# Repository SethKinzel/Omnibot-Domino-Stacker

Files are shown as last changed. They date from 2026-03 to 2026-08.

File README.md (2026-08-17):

# Omnibot Domino Stacker

A modification for the **CrunchLabs Hack Pack Omnibot Forklift** that allows the robot to pick up and stack dominoes.

The project replaces the standard remote-control setup with an **Arduino-based wireless controller** using two joysticks. This allows for **variable-speed movement and rotation**, giving much finer control when positioning the robot and stacking dominoes.

Domino Stacker

## Features

* Wireless control using **NRF24L01** transceiver modules
* Arduino-based remote controller
* Dual joystick control
* Variable-speed forward/reverse/left/right movement
* Variable-speed rotation
* Servo-controlled domino stacking mechanism
* 3D-printed modifications and components

## Parts

### Robot

* **CrunchLabs Hack Pack Omnibot Forklift**
* 1 × Standard **SG90 Micro Servo**
* 1 × NRF24L01 Transceiver Module
* 1 × Decoupling capacitor (10 µF–100 µF recommended)
* Counterweight material (I used large bolts)
* Wires
* Access to a 3D printer

### Remote Control

* Arduino Nano
* 1 × NRF24L01 Transceiver Module
* 1 × Decoupling capacitor (10 µF–100 µF recommended)
* 2 × Joysticks (KY-023 or similar)
* Wires

### NRF24L01 Modules

[NRF24L01 Transceiver Modules on Amazon](https://www.amazon.com/dp/B00LX47OCY/ref=as_li_tl?ie=UTF8&tag=tyche-8392-20&psc=1)

The decoupling capacitors are used to help provide stable power to the NRF24L01 modules.

[100 µF Electrolytic Capacitors – SparkFun](https://www.sparkfun.com/electrolytic-decoupling-capacitors-100uf-25v.html)

This tutorial provides additional information about using the NRF24L01 with Arduino:

[NRF24L01 Arduino Wireless Communication Tutorial](https://www.instructables.com/NRF24L01-Tutorial-Arduino-Wireless-Communication/)

## Arduino Libraries

The project uses the following Arduino libraries:

* **RF24** by TMRh20  
  Install through the Arduino Library Manager or from the [RF24 GitHub repository](https://github.com/tmrh20/RF24/)

* **MapFloat** by radishlogic  
  [MapFloat GitHub repository](https://github.com/radishlogic/MapFloat)

* **OneButton** by Matthias Hertel  
  Install through the Arduino Library Manager or from the [OneButton GitHub repository](https://github.com/mathertel/OneButton)

* **EasyJoystick** by Seth Kinzel  
  Install through the Arduino Library Manager or from the [EasyJoystick GitHub repository](https://github.com/SethKinzel/EasyJoystick)

## Getting Started

### 1. Remove Parts for Installation and Rewiring

Start by removing the parts of the Omnibot that need to be taken off to install the new **lift/domino stacker assembly**.

Removing these parts also gives you better access to the electronics and wiring, which you will need for the rewiring steps that follow.

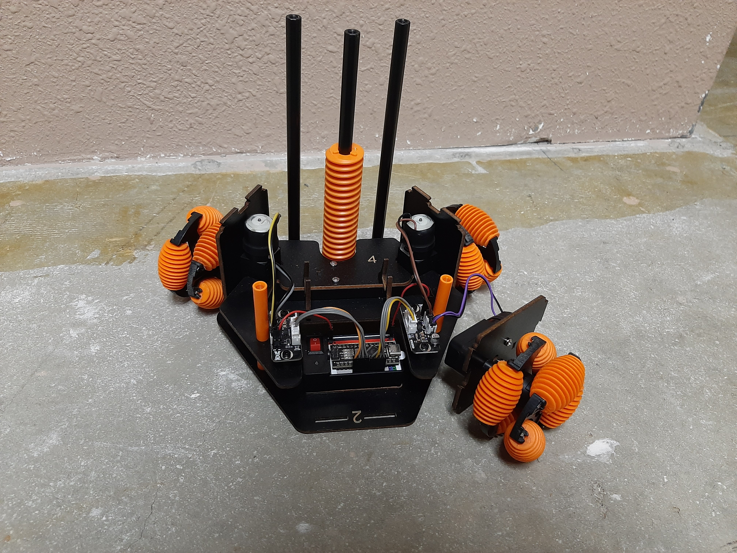
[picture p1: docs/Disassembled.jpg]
Omnibot disassembled


### 2. Print the 3D Parts

Print the following files from the `3D` folder:
* Main Body.stl
* Slider.stl
* `DOMNO_Servo_Horn.stl` from the line following domino robot (2nd hackpack). I have included it here.
* Domino.stl  
I had success printing these standing upright with a small brim, but there might be other ways to do it.
Do a few small batches first, and make sure that they stand up and don't get caught.
Be sure to use enough elephant foot compensation.  
The robot takes 70 dominoes, but it might be good to have a few extra.

* (optional) Magazine.stl  
Allows the robot to stack multiple tiles of dominoes without reloading.  
You can stack multiple magazines on top of each other, until it gets too heavy.  
Print upside down, and be sure to block support from the holes in the four corners.

* (optional) folder `3D/Different size dominoes`
Different size dominoes

### 3. Install the new lift/domino mechanism

Assemble as shown:

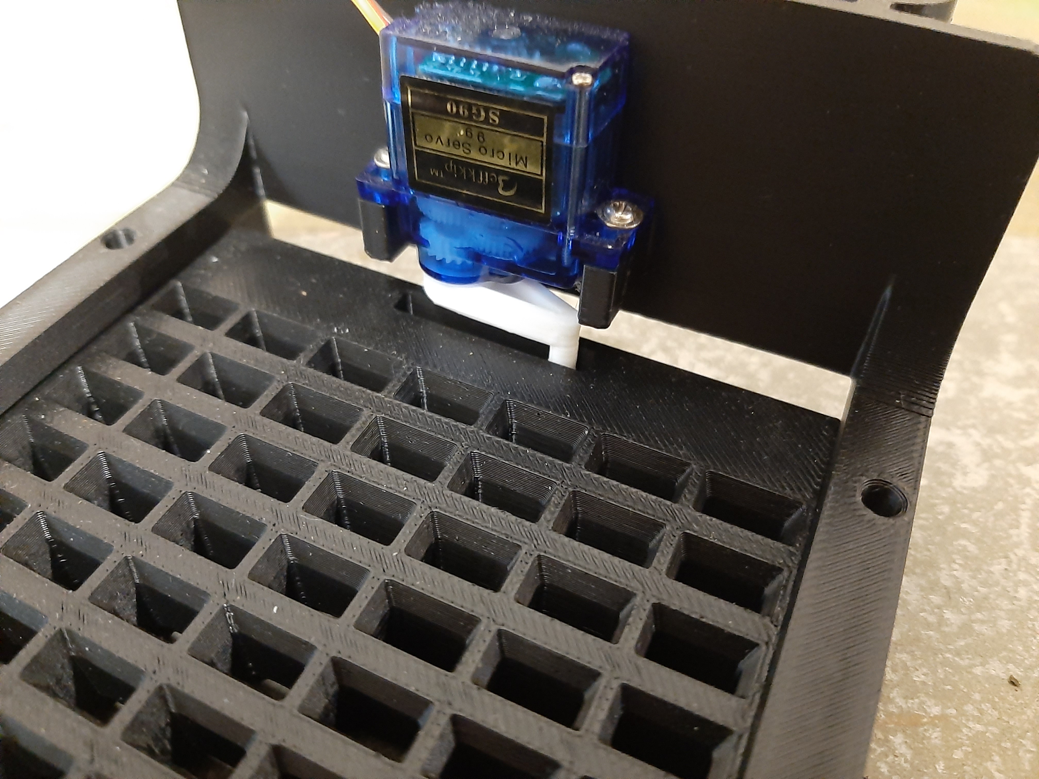
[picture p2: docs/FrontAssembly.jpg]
How to assemble


If using the magazine, put the side with the narrow border towards the robot.

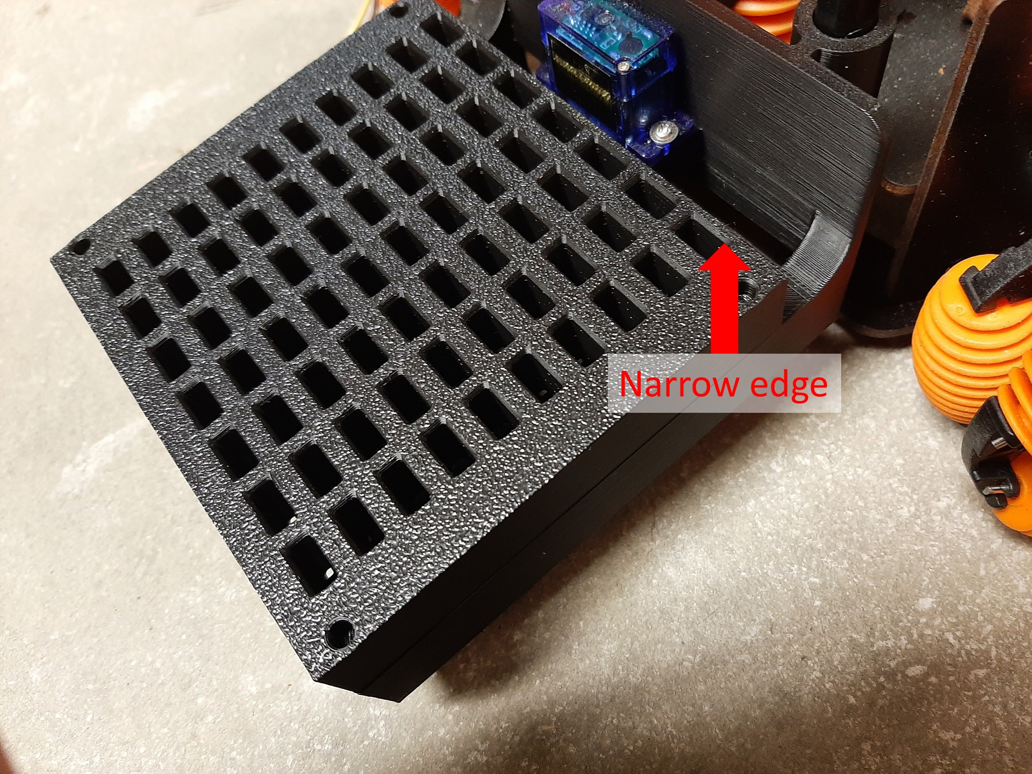
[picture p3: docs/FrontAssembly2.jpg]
How to install magazine


### 4. Rewire the Omnibot

* Swap ribbon cables

  The Domino Stacker uses a servo, which occupies one of the Arduino's hardware timer outputs. The stock Omnibot wiring uses PWM on pin 9, which conflicts with the servo.

  To avoid changing the existing ribbon cables, the motor assignments are rearranged so that the three drive motors use PWM-capable pins while the lift motor (which only needs full-speed up/down movement) uses the remaining output.

  The Omnibot has two ribbon cables connecting the Arduino board to the motor driver boards.

  **Swap the two ribbon cables on the motor driver boards only.**

  > **Important:** Leave the Arduino ends plugged in exactly as they are. Only unplug and swap the ends connected to the two motor driver boards.

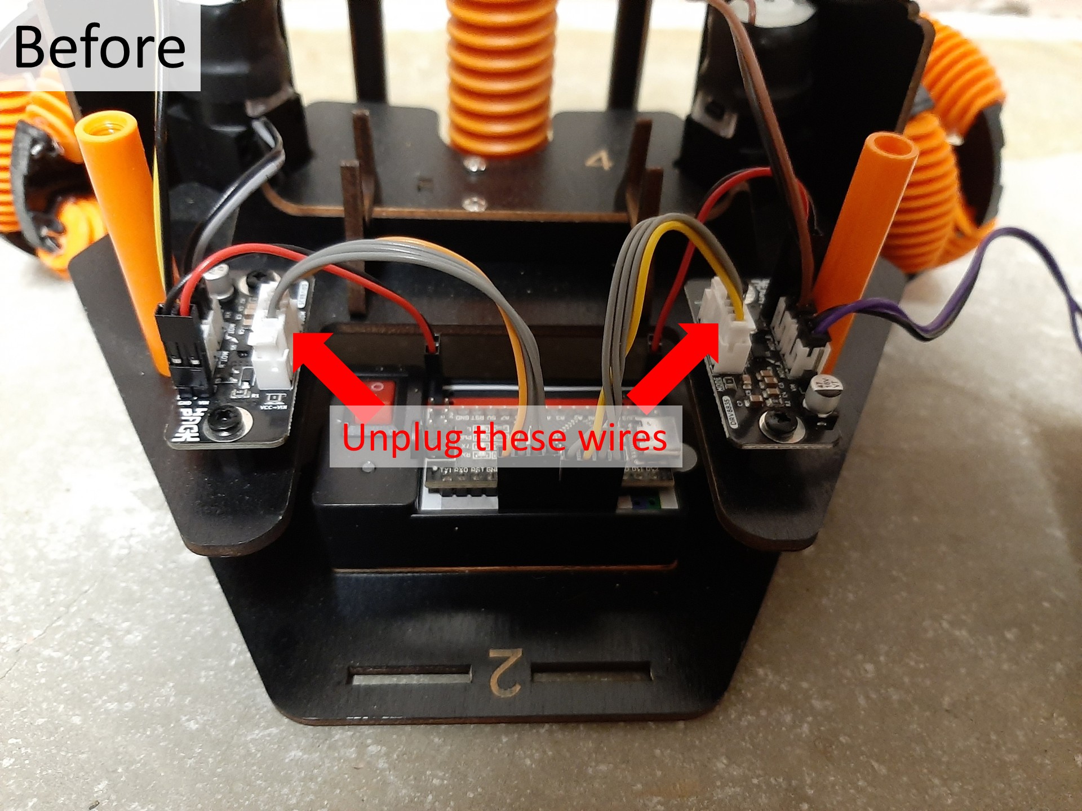
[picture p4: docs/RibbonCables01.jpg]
Switching the ribbon cables
  
  
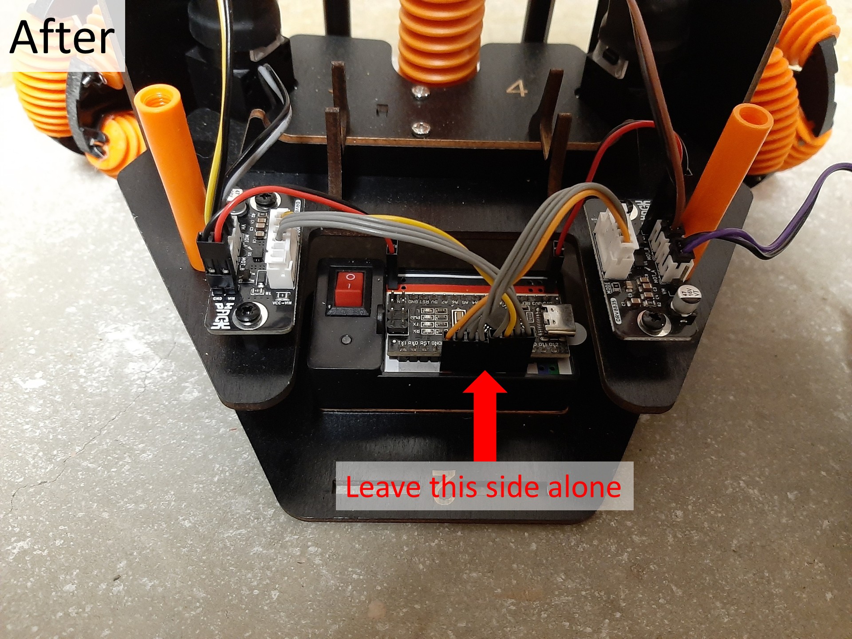
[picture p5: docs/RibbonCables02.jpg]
Switching the ribbon cables
  

* Swap yellow/gray motor cables

  On the **left motor driver board**, swap these two cables:

  * Yellow cable from **Motor 1**
  * Gray cable from the **Lift Motor**

  After swapping them, the motor connections should match the new pin assignments used by the software.

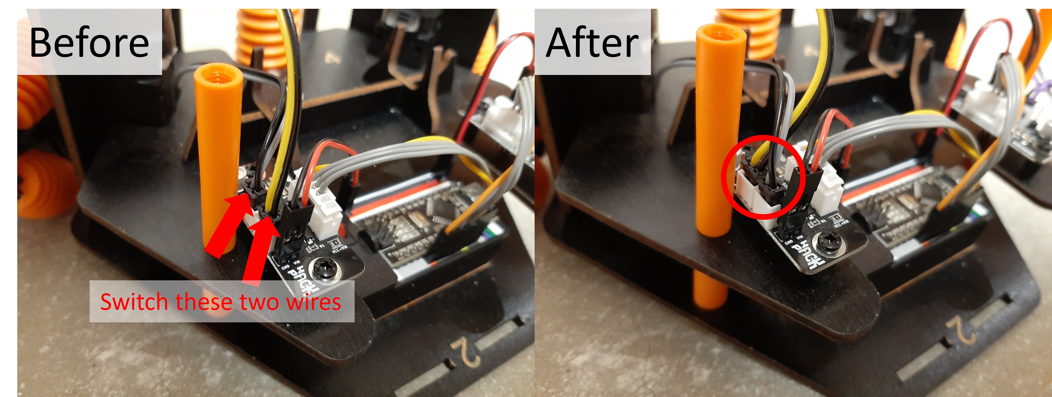
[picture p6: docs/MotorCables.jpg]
Switching the motor cables
  

* Add the Receiver and Servo

  Once the rewiring is complete, add the **receiver** and the **servo** according to the wiring diagram.

  Make sure all connections match the diagram before powering on the robot.

  #### ⚠️ Warning – NRF24L01 Power

  The **NRF24L01 requires 3.3V**. Connect VCC to the Arduino's **3.3V pin, NOT 5V**.

  I connected both the transceiver and capacitor to the 3.3V pin on the Arduino using a simple Y-shaped wire made by soldering **one male wire to two female wires**.

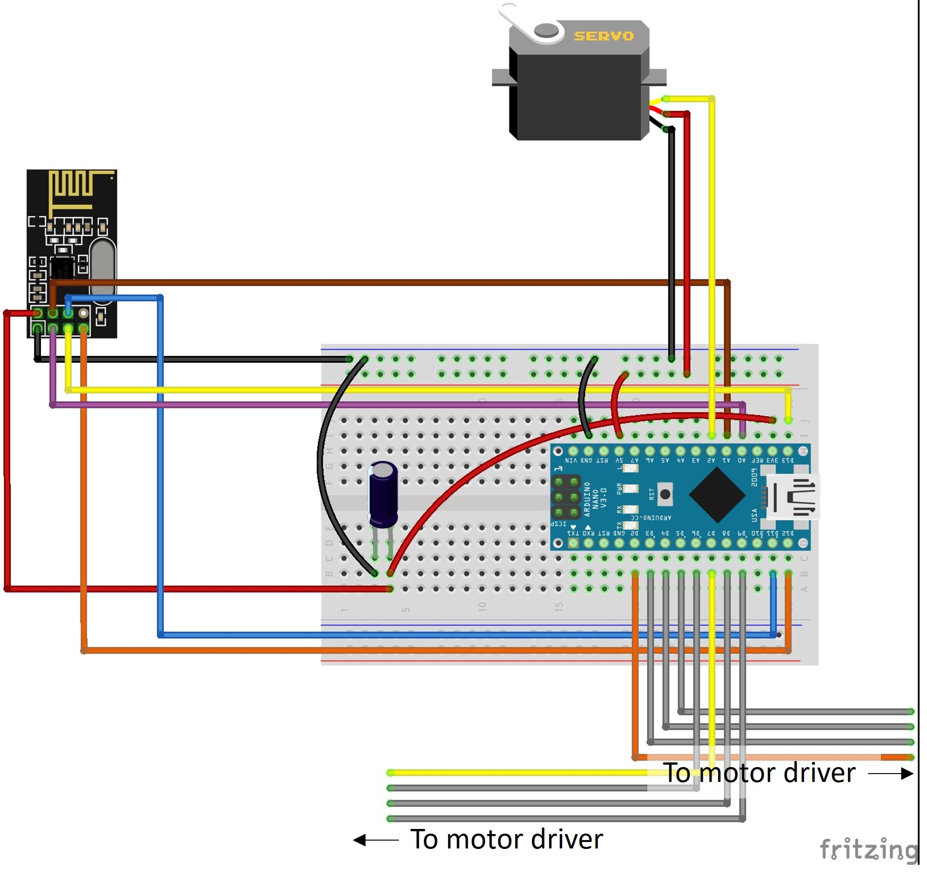
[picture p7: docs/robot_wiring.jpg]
Robot wiring diagram
  

### 5. Add Counterweight

Reassemble the robot and install a counterweight at the back. The counterweight helps maintain enough friction on the back wheel.

### 6. Build the remote controller

Follow the wiring diagram:

#### ⚠️ Warning – NRF24L01 Power

The **NRF24L01 requires 3.3V**. Connect VCC to the Arduino's **3.3V pin, NOT 5V**.

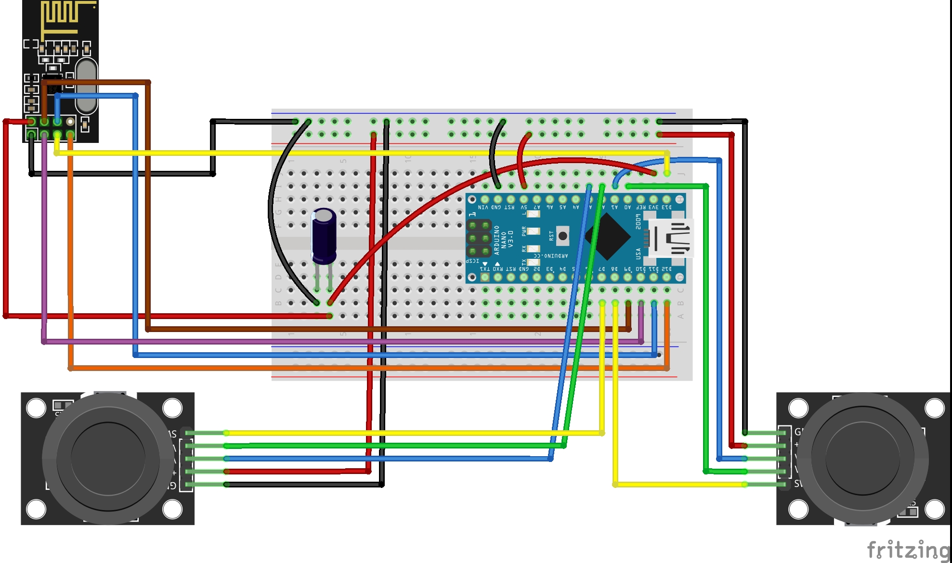
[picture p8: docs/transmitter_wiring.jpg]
Remote control wiring diagram


### 7. Install the required libraries

Install all of the libraries listed above using the Arduino Library Manager or their respective GitHub repositories.

### 8. Upload the Arduino sketches

Upload `Omnibot_Domino_Stacker.ino` to the Omnibot, and `OmniRemote_Transmitter.ino` to the remote control.

### 9. Power on and connect

Turn on the Omnibot and remote controller. The NRF24L01 modules should establish a wireless connection, allowing the robot to be controlled using the joysticks.

## Controls

| Control | Function |
| --- | --- |
| Left joystick | Movement |
| Right joystick left/right | Rotation |
| Right joystick up/down | Raise/lower dominoes |
| Right joystick button | Drop dominoes / reset domino holder |

## Fine-tuning

You may need to adjust the `SERVO_DROP` and `SERVO_RESET` constants in `Omnibot_Domino_Stacker/config.h` to fine-tune the servo positions.

## Optional Components

The following components are **completely optional** and are disabled by default. They do not affect the basic operation of the robot.

### LCD

I had an I2C LCD (from the label maker Hack Pack) already attached to the Arduino I used for the remote control, so I added support for it. It simply displays **"Remote Control"**.

You do not need an LCD to use the project.

The LCD can be enabled or disabled by editing the following line in `OmniRemote_Transmitter.ino`:

```cpp
#define USE_LCD 0
```

Set this to `1` to enable the LCD:

```cpp
#define USE_LCD 1
```

Wire the I2C LCD to the I2C port on A4 and A5

hd44780 library by Bill Perry — required only when USE_LCD is set to 1  
Install through the Arduino Library Manager or from the [hd44780 GitHub repository](https://github.com/duinoWitchery/hd44780)

If you are not using an LCD, you **do not need to install the hd44780 library**.

### LED Strip

There is also an optional LED strip (taken from the sand garden Hack Pack) that displays a simple color pattern. The LEDs are purely decorative and are not required for controlling the robot.

LED support can be enabled by uncommenting this line in `OmniRemote_Config.h`:

```cpp
#define USELEDS
```

When LED support is not needed, leave the line commented out.

Wire the led strip to pin 2

FastLED library by Daniel Garcia - required only when USELEDS is defined.  
Install through the Arduino Library Manager or from the [FastLED GitHub repository](https://github.com/FastLED/FastLED)

If `USELEDS` is not defined, you **do not need to install the FastLED library**.

## Project Status

This project is a personal modification of the CrunchLabs Hack Pack Omnibot Forklift.

The repository contains the hardware modifications, Arduino code, and 3D-printed parts needed to build the domino stacker.

## Credits

* **CrunchLabs** – Omnibot Hack Pack Forklift
* **TMRh20** – RF24 library
* **radishlogic** – MapFloat library
* **Matthias Hertel** – OneButton library
* **Seth Kinzel** – EasyJoystick library
* **Bill Perry** – hd44780 library
* **Daniel Garcia** – FastLED library

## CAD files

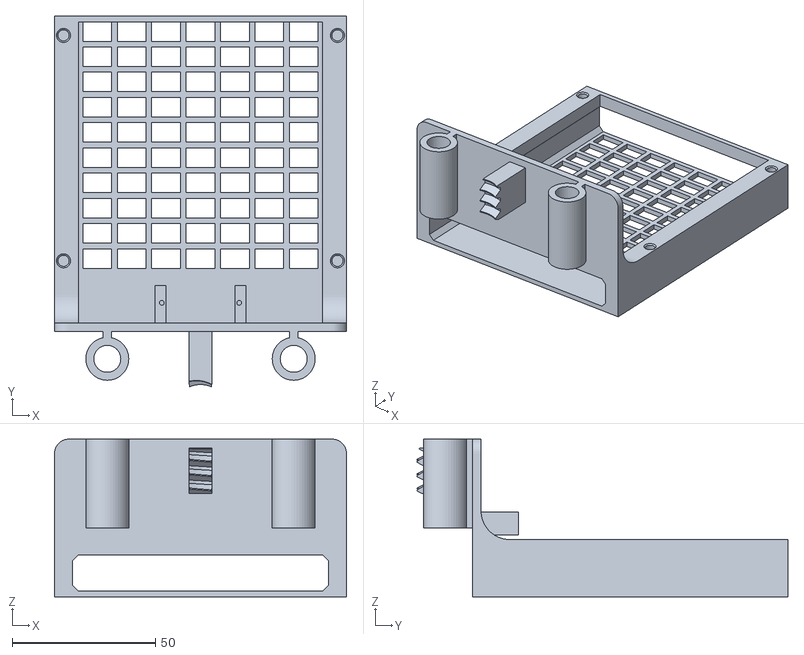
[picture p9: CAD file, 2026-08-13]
3D/Main Body.stl
101.8 x 129.3 x 55.0

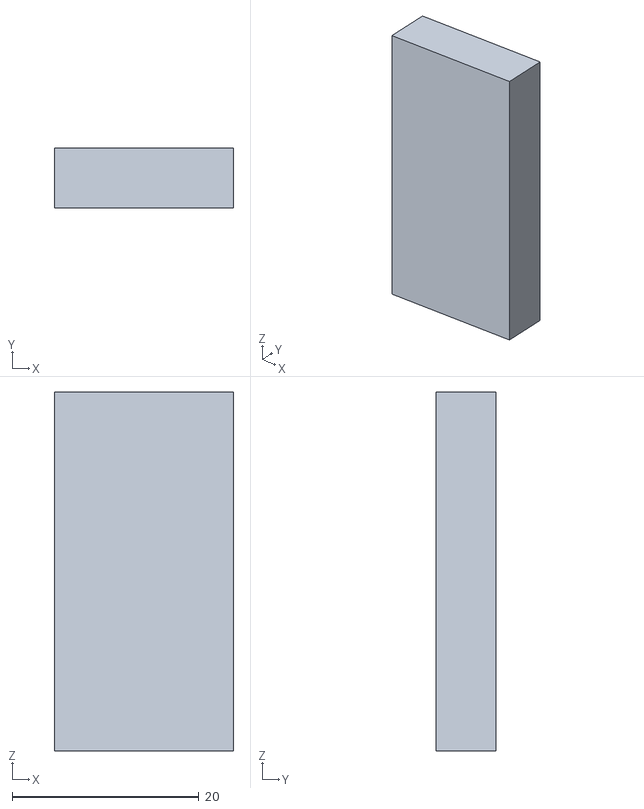
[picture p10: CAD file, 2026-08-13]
3D/Different size dominoes/Size -1.stl
19.2 x 6.40 x 38.4

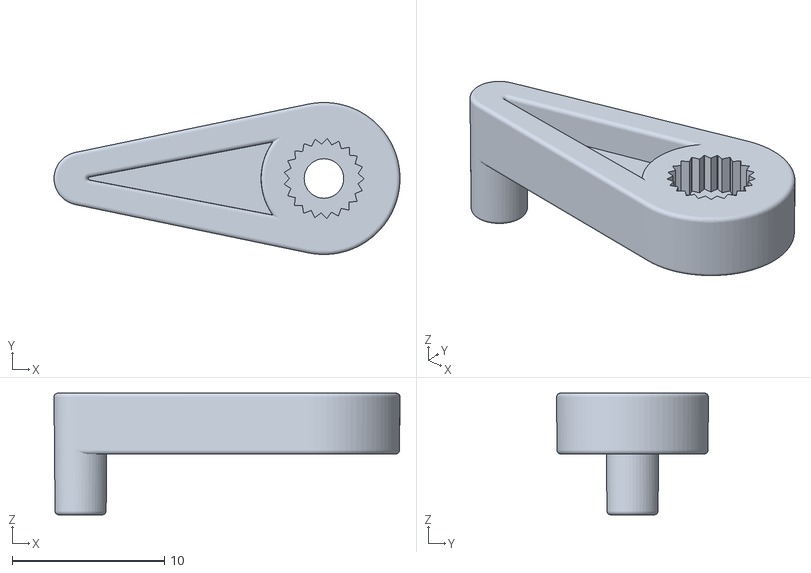
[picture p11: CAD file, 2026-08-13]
3D/DOMNO_Servo_Horn.stl
22.7 x 9.99 x 8.00

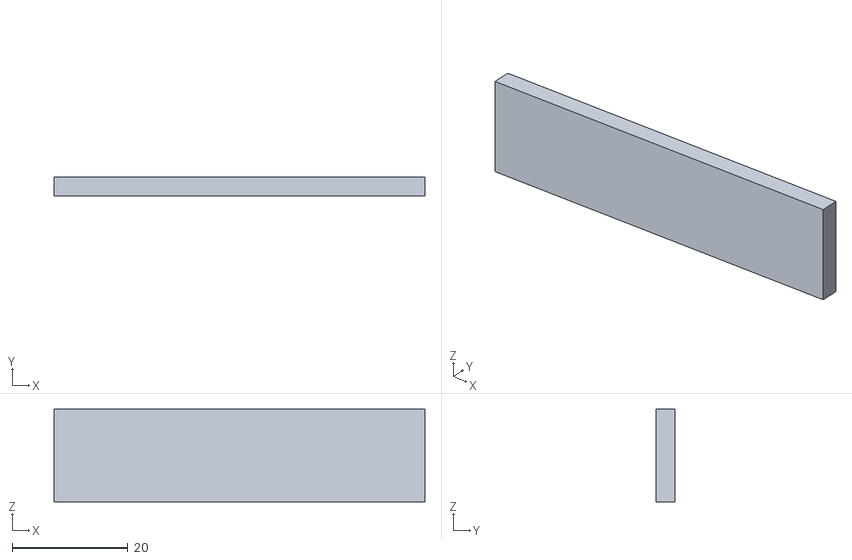
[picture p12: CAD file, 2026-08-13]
3D/Different size dominoes/Wide Domino 3.stl
64.0 x 3.20 x 16.0

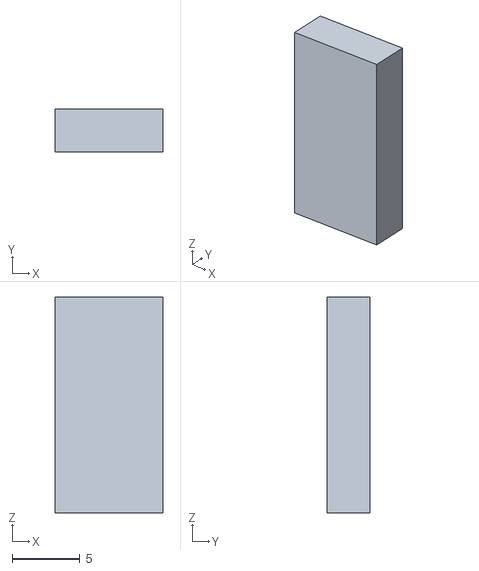
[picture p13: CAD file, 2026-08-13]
3D/Domino.stl
8.00 x 3.20 x 16.0

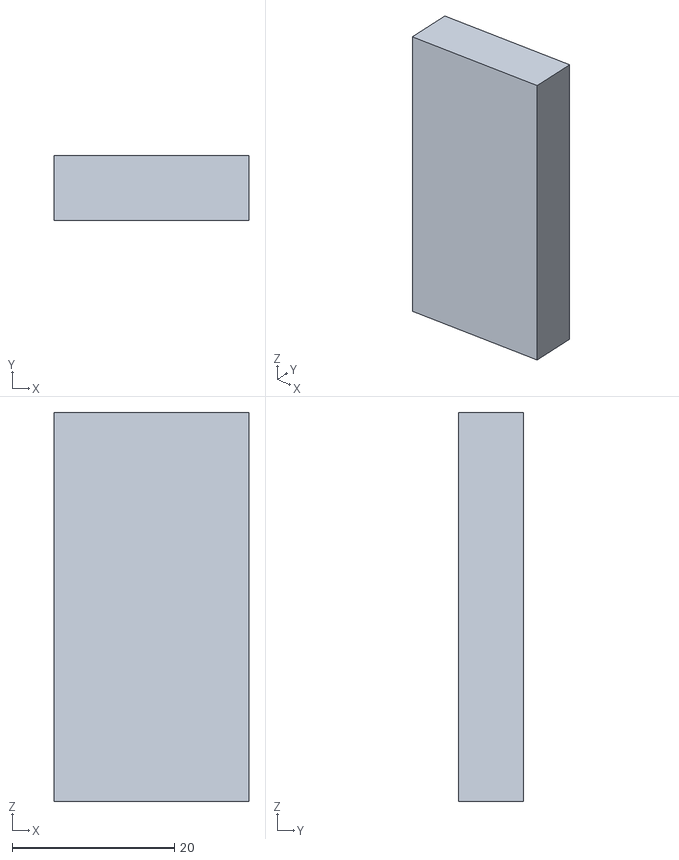
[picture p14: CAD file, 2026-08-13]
3D/Different size dominoes/Normal Size.stl
24.0 x 8.00 x 48.0

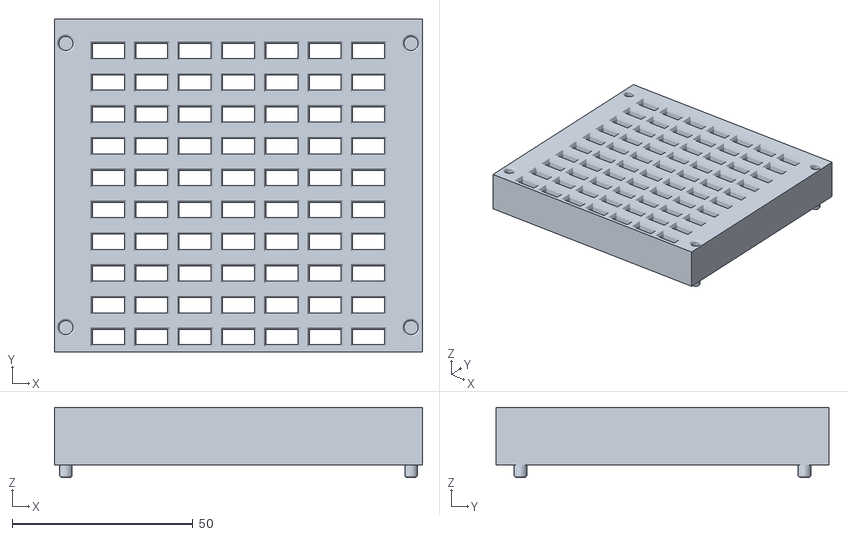
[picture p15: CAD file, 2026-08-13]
3D/Magazine.stl
101.8 x 92.1 x 19.5

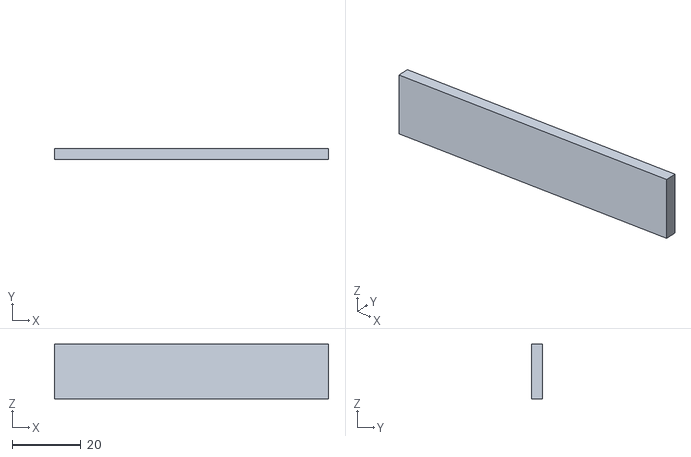
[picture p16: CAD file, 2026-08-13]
3D/Different size dominoes/Wide Domino 4.stl
80.0 x 3.20 x 16.0

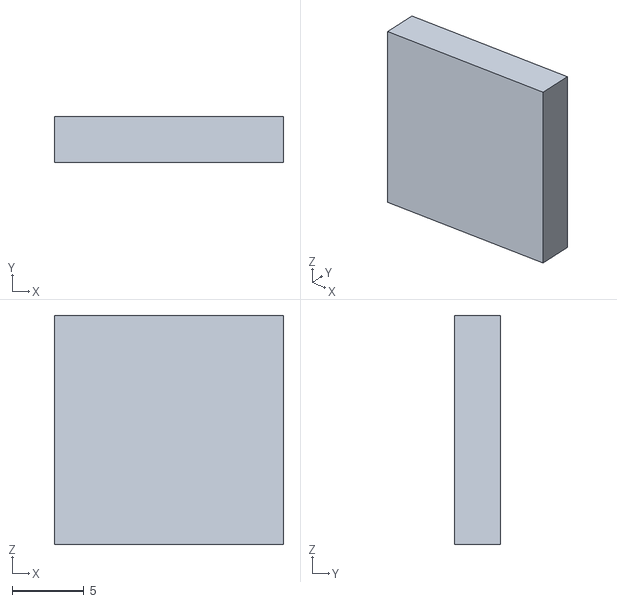
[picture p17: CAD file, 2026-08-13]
3D/Different size dominoes/Wide Domino 1.stl
16.0 x 3.20 x 16.0

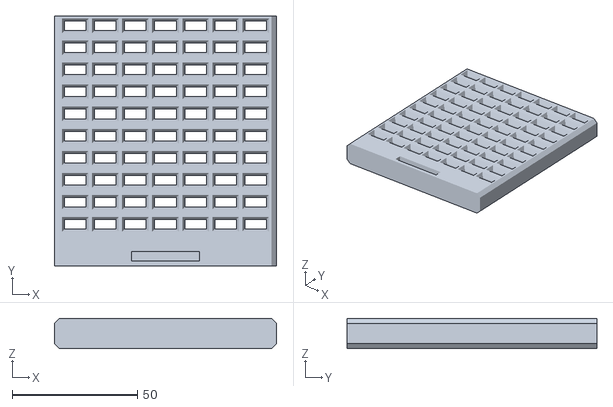
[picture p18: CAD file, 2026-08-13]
3D/Slider.stl
88.6 x 99.8 x 12.0

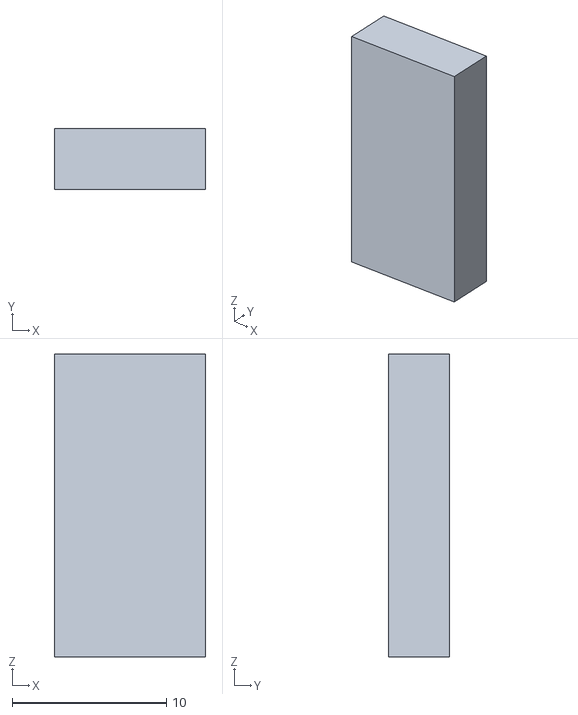
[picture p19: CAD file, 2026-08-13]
3D/Different size dominoes/Size -4.stl
9.83 x 3.93 x 19.7

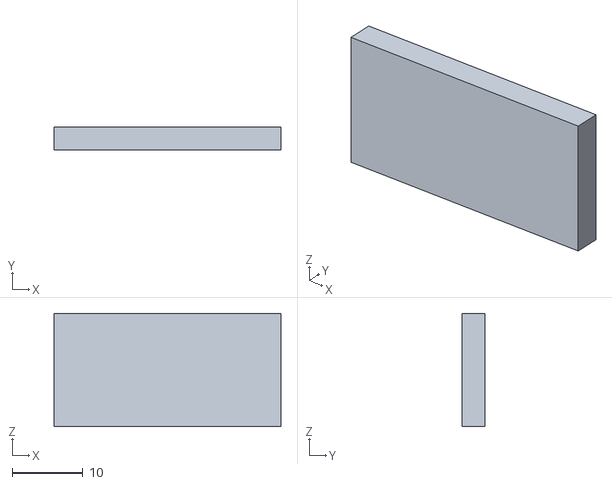
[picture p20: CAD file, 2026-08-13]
3D/Different size dominoes/Wide Domino 2.stl
32.0 x 3.20 x 16.0

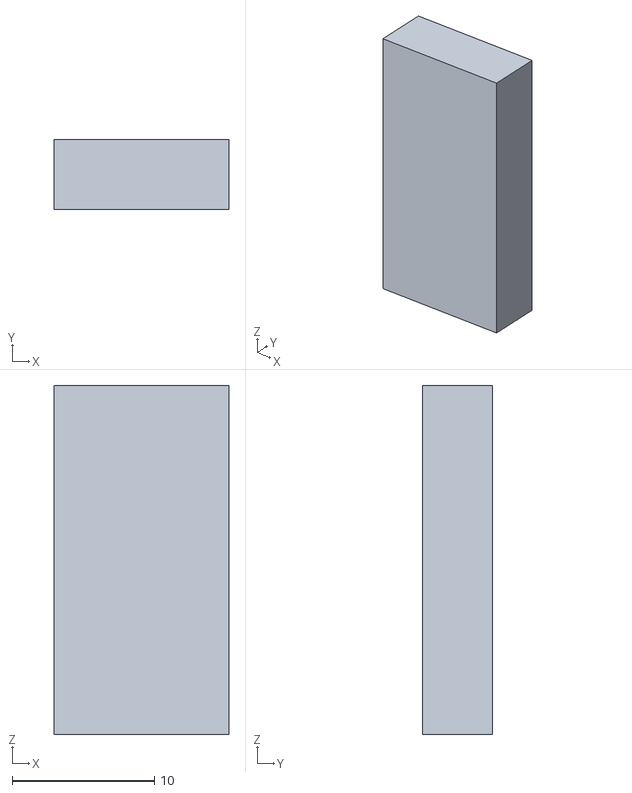
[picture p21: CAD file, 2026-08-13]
3D/Different size dominoes/Size -3.stl
12.3 x 4.92 x 24.6

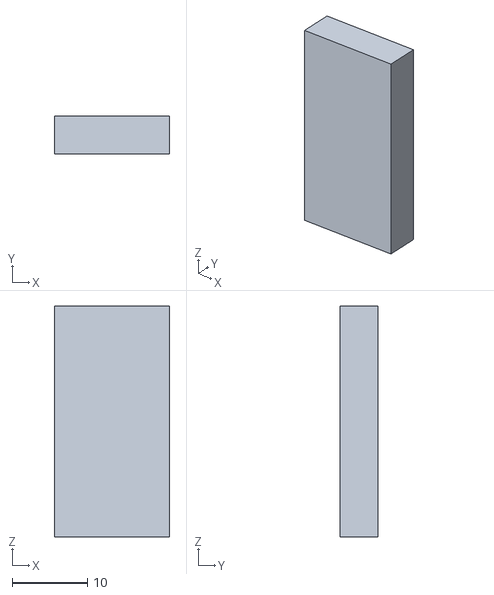
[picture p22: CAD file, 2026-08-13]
3D/Different size dominoes/Size -2.stl
15.4 x 5.12 x 30.7

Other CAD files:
3D/Different size dominoes/Size 1.stl
3D/Different size dominoes/Size 2.stl
3D/Different size dominoes/Size 3.stl
3D/Different size dominoes/Size 4.stl

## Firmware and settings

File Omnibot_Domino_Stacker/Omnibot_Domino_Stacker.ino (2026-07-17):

/*
A hack to the CrunchLabs Hack Pack Omnibot Forklift that allows it to stack dominoes.  
It uses an arduino and two joysticks as the remote control to allow for variable-speed movement and rotation  
*/

#include "config.h"
#include <SPI.h>
#include <RF24.h>
#include <nRF24L01.h>
#include "RC_Payload.h"
#include <Servo.h>
#include <MapFloat.h>

#define SIN60 0.86602540378443864676372317075294

//>>>>>>>>>>>>>>>>>>>>>>>>>> KEY ROBOT VARIABLES <<<<<<<<<<<<<<<<<<<<<<<<<<<<<<<
// drive vector (in velocities) {v_x, v_y, omega}
struct VECTOR {
  float x, y, o;
};

VECTOR vSpeed;
// for forklift, -1 for lower, 0 for stay, 1 for move up
int moveFork = 0;

// stores each calculated wheel speed for a given commanded vector {w1, w2, w3}.
float wheelSpeeds[3];

// receiver
RF24 radio(CE_PIN, CSN_PIN); // CE, CSN
// servo
Servo servo1;

// >>>>>>>>>>>>>>>>>>>>>>>>>>>>>>>>> SETUP <<<<<<<<<<<<<<<<<<<<<<<<<<<<<<<<<<<<<
void setup() {
  servo1.attach(SERVO_PIN);
  servo1.write(SERVO_RESET);

  radio.begin();
  radio.setPALevel(RF24_PA_MIN);
  radio.setPayloadSize(sizeof(payload));
  radio.openReadingPipe(0, address);
  radio.startListening();
}



// >>>>>>>>>>>>>>>>>>>>>>>>>>>>>>>>> LOOP <<<<<<<<<<<<<<<<<<<<<<<<<<<<<<<<<<<<<<
void loop() {
  handleRadio();
  moveBot();
}



// >>>>>>>>>>>>>>>>>>>>> RADIO COMMAND PROCESSING <<<<<<<<<<<<<<<<<<<<<<<<<<<<<<
void handleRadio() {
  if (!radio.available()) return; // only run the rest of the function if there is new data
  radio.read(&payload, sizeof(payload));

  //set x, y, and omega vectors
  int32_t x = payload.lx - 512; // needs int32 for radius calculation
  int32_t y = payload.ly - 512;
  int32_t radius = sqrt(x*x + y*y); // pythagorean theorem
  if (abs(radius < joystickCenterThreshold)) {
    x = 0;
    y = 0;
  }
  int o = payload.rx - 512;
  if (abs(o) < joystickCenterThreshold) o = 0;

  const int xyScaling = 430;
  const int oScaling = 500;
  vSpeed.x = mapFloat(x, -xyScaling, xyScaling, 1, -1);
  vSpeed.y = mapFloat(y, -xyScaling, xyScaling, 1, -1);
  vSpeed.o = mapFloat(o, -oScaling, oScaling, -1, 1);

  if(payload.ry > 512 + joystickCenterThreshold) { //Fork Up
    moveFork = 1;
  } else if(payload.ry < 512 - joystickCenterThreshold) { //Fork Down
    moveFork = -1;
  } else {
    moveFork = 0;
  }

  if(payload.rb1) {
    servo1.write((servo1.read() == SERVO_RESET) ? SERVO_DROP : SERVO_RESET);
  }
}


// >>>>>>>>>>>>>>>>>>>>>>>> ROBOT ACTION FUNCTIONS <<<<<<<<<<<<<<<<<<<<<<<<<<<<<
// prepare motors to coorinate bot movements
void moveBot(){
  getWheelSpeeds();
  driveWheels();
  driveLift();
}

// >>>>>>>>>>>>>>>>>>>>>>>>>> INVERSE KINEMATICS <<<<<<<<<<<<<<<<<<<<<<<<<<<<<<<
// calculates speed of each wheel based of commanded speed vector. Forumlas are in the linked reading!
void getWheelSpeeds() {
  wheelSpeeds[2] = -0.5 * vSpeed.x + SIN60 * vSpeed.y + vSpeed.o;
  wheelSpeeds[0] = -0.5 * vSpeed.x - SIN60 * vSpeed.y + vSpeed.o;
  wheelSpeeds[1] =  1.0 * vSpeed.x + vSpeed.o;
}

// Addresses motor controllers to drive wheels at caclulated speeds
void driveWheels(){  
  // drive all motors at calculated speeds
  float topWheelSpeed = max(max(abs(wheelSpeeds[0]), abs(wheelSpeeds[1])), abs(wheelSpeeds[2]));
  int16_t intSpeeds[3];

  for(int8_t i = 0; i < 3; i++) {
    if (topWheelSpeed > 1) {
      wheelSpeeds[i] = wheelSpeeds[i] / topWheelSpeed;
    }
    wheelSpeeds[i] = mapFloat(wheelSpeeds[i], -1, 1, -255, 255);
    intSpeeds[i] = constrain(wheelSpeeds[i], -255, 255);
    if((flipM1 && i == 0) || (flipM2 && i == 1) || (flipM3 && i == 2)) {
      intSpeeds[i] = - intSpeeds[i];
    }
  }

  if(intSpeeds[0] < 0){
    digitalWrite(M1_DIR, LOW);
  } else {
    digitalWrite(M1_DIR, HIGH);
  }
  analogWrite(M1_PWM, abs(intSpeeds[0]));

  if(intSpeeds[1] < 0){
    digitalWrite(M2_DIR, LOW);
  } else {
    digitalWrite(M2_DIR, HIGH);
  }
  analogWrite(M2_PWM, abs(intSpeeds[1]));

  if(intSpeeds[2] < 0){
    digitalWrite(M3_DIR, LOW);
  } else {
    digitalWrite(M3_DIR, HIGH);
  }
  analogWrite(M3_PWM, abs(intSpeeds[2]));
}

// Moves lift motor. full forward, full back, or stopped.
void driveLift(){
  if(flipM4){
    if(moveFork > 0){
      digitalWrite(LIFT_DIR, LOW);
      analogWrite(LIFT_PWM, 255);
    } else if(moveFork < 0){
      digitalWrite(LIFT_DIR, HIGH);
      analogWrite(LIFT_PWM, 255);
    } else{
      digitalWrite(LIFT_DIR, HIGH);
      analogWrite(LIFT_PWM, 0);
    }
  } else {
    if(moveFork > 0){
      digitalWrite(LIFT_DIR, HIGH);
      analogWrite(LIFT_PWM, 255);
    } else if(moveFork < 0){
      digitalWrite(LIFT_DIR, LOW);
      analogWrite(LIFT_PWM, 255);
    } else{
      digitalWrite(LIFT_DIR, LOW);
      analogWrite(LIFT_PWM, 0);
    }
  }
}

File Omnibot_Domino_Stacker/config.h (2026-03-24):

const int joystickCenterThreshold = 75;
// motor flipping
bool flipM1 = false;
bool flipM2 = false;
bool flipM3 = false;
bool flipM4 = true;

// servo positions
const int SERVO_DROP = 92;
const int SERVO_RESET = 74;

// pin definitions
#define M1_DIR 7
#define M1_PWM 6
#define M2_DIR 2
#define M2_PWM 3
#define M3_DIR 4
#define M3_PWM 5

#define LIFT_DIR 8
#define LIFT_PWM 9

#define CE_PIN A0
#define CSN_PIN A1

#define SERVO_PIN A2

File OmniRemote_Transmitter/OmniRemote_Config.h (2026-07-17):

#ifndef SK_REMOTEPINDEFINITIONS_h
#define SK_REMOTEPINDEFINITIONS_h

#include <Arduino.h>


// Pin Definitions
constexpr int8_t LEFT_JOYSTICK_X_PIN = A3;
constexpr int8_t LEFT_JOYSTICK_Y_PIN = A2;
constexpr int8_t RIGHT_JOYSTICK_X_PIN = A1;
constexpr int8_t RIGHT_JOYSTICK_Y_PIN = A0;
constexpr int8_t LEFT_BUTTON_1_PIN = 7;
constexpr int8_t RIGHT_BUTTON_1_PIN = 8;
constexpr int8_t LED_DATA_PIN = 2;
constexpr int8_t CE_PIN = 10;
constexpr int8_t CSN_PIN = 9;
constexpr int8_t BUZZER_PIN = 3;
constexpr int8_t RANDOM_PIN = A6;

// Configuration
constexpr bool LEFT_JOYSTICK_X_FLIPED = true;
constexpr bool LEFT_JOYSTICK_Y_FLIPED = false;
constexpr bool RIGHT_JOYSTICK_X_FLIPED = false;
constexpr bool RIGHT_JOYSTICK_Y_FLIPED = true;

constexpr int NUM_LEDS = 8;          //Number of LEDs in the bar.
// #define USELEDS // uncomment this line if you have an led bar.

#endif

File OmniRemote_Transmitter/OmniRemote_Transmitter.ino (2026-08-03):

// Libraries
#include <SPI.h>
#include <RF24.h>
#include <nRF24L01.h>

#include <OneButton.h>
#include "RC_Payload.h"
#include "OmniRemote_Config.h"


#pragma region SERIAL FUNCTIONS

  // In your code, rather than using Serial.print() or Serial.println(), use their aliases defined below (e.g., SERIAL_PRINTLN()):

#define USE_SERIAL 0  // 1 or 0 to tell whether or not to print stuff to the serial monitor.
                      // Set to 1 when testing and back to 0 when done testing.

#if USE_SERIAL
  #define SERIAL_PRINT(x)     Serial.print(x)
  #define SERIAL_PRINTLN(x)   Serial.println(x)
  #define SERIAL_BEGIN(baud)  Serial.begin(baud)

  void printSerial() {
    Serial.print(F("lx: "));
    printWithSpaces(payload.lx, 4);
    Serial.print(F(", ly: "));
    printWithSpaces(payload.ly, 4);
    Serial.print(F(", rx: "));
    printWithSpaces(payload.rx, 4);
    Serial.print(F(", ry: "));
    printWithSpaces(payload.ry, 4);
    Serial.print(F(", lb1: "));
    printWithSpaces(payload.lb1, 1);
    Serial.print(F(", rb1: "));
    printWithSpaces(payload.rb1, 1);
    Serial.println();
  }

  void printWithSpaces(int16_t val, int16_t spaces) {
    String str = String(val);
    for (int16_t i = str.length(); i < spaces; i++) {
      Serial.print(" ");
    }
    Serial.print(str);
  }

#else
  #define SERIAL_PRINT(x)
  #define SERIAL_PRINTLN(x)
  #define SERIAL_BEGIN(baud)
  #define printSerial()
  #define printWithSpaces(val, spaces)
#endif

#pragma endregion SERIAL FUNCTIONS

#pragma region LCD_FUNCTIONS

#define USE_LCD 0 // 1 or 0 to tell whether or not to use a lcd

#if USE_LCD
  #include <Wire.h>
  #include <hd44780.h>                        // main hd44780 header
  #include <hd44780ioClass/hd44780_I2Cexp.h>  // i2c expander i/o class header
  hd44780_I2Cexp lcd; // declare lcd object: auto locate & auto config expander chip
  #define LCD_PRINT(x)     lcd.print(x)
  #define LCD_BEGIN(x, y)  lcd.begin(x, y)
#else
  #define LCD_PRINT(x)
  #define LCD_BEGIN(x, y)
#endif


#pragma endregion LCD_FUNCTIONS

#pragma region LedDisplayClass
#ifdef USELEDS

/////////////////////////////////////////////////////////////////////////////////////////////////////////////////////////////////////////////////////////
/*
This is a class that contains all the functions and data required to handle the LED display bar.
*/
/////////////////////////////////////////////////////////////////////////////////////////////////////////////////////////////////////////////////////////
#include <FastLED.h>                        //Controls the RGB LEDs
const int MAX_BRIGHTNESS = 40;  //Brightness values are 8-bit for a max of 255 (the range is [0-255]), this sets default maximum to 40 out of 255.

class LedDisplay {
private:
  CRGB leds[NUM_LEDS];        //array that holds the state of each LED

public:
  //This is the constructor. It's called when a new instance of the class is created, and handles setting things up for use.
  LedDisplay() {              
    FastLED.addLeds<WS2812B, LED_DATA_PIN, GRB>(leds, NUM_LEDS);
    FastLED.setBrightness(MAX_BRIGHTNESS);
    FastLED.clear();
  }

/**
 * @brief Animates an LED bouncing pattern during the homing process and flashes green when homing is complete.
 *
 * This function animates a bouncing light pattern on the LEDs to indicate that the gantry is in the process of homing. 
 * Once homing is complete, the LEDs flash green to signal completion. The function can block execution briefly during the 
 * flashing portion after homing is done.
 *
 * @param homingComplete A boolean flag indicating whether the homing process is complete. If set to false, the animation continues. 
 * If set to true, the LEDs flash green to indicate completion.
 *
 * The animation consists of a bouncing light pattern with a color that changes over time. When the gantry finishes homing, 
 * the LEDs flash green in a blocking manner for a brief period.
 */
  void homingSequence(bool homingComplete = false) {
    static unsigned long lastUpdate = 0;

    const byte fadeAmount = 150;
    const int ballWidth = 2;
    const int deltaHue  = 4;

    static byte hue = HUE_RED;
    static int direction = 1;
    static int position = 0;
    static int multiplier = 1;

    FastLED.setBrightness(MAX_BRIGHTNESS);

    if (!homingComplete) {                      //If the homing sequence is not complete, animate this pattern.
      if (millis() - lastUpdate >= 100) {
        hue += deltaHue;
        position += direction;

        if (position == (NUM_LEDS - ballWidth) || position == 0) direction *= -1;

        for (int i = 0; i < ballWidth; i++) {
          leds[position + i].setHue(hue);
        }

        // Randomly fade the LEDs
        for (int j = 0; j < NUM_LEDS; j++) {
          //if (random(10) > 3)
          leds[j] = leds[j].fadeToBlackBy(fadeAmount);  
        }
        FastLED.show();
        lastUpdate = millis();
      }
    } else {                                    //if the homing sequence is complete, indicate that by flashing the LEDs briefly.
      for (int i = 0; i < NUM_LEDS; i++) {
        leds[i] = CRGB::Green;
      }
      
      for (int j = 0; j < 8; j++) {
        FastLED.setBrightness(constrain(MAX_BRIGHTNESS * multiplier, 0, MAX_BRIGHTNESS));
        multiplier *= -1;
        FastLED.show();
        delay(100);
      }
    }
  }
};

LedDisplay display;  // Create an instance of the LedDisplay class that controls the RGB LEDs.

#endif
#pragma endregion LedDisplayClass

// Objects
OneButton leftButton1;
OneButton rightButton1;

RF24 radio(CE_PIN, CSN_PIN); // CE, CSN


void setup() {
  SERIAL_BEGIN(115200);
  LCD_BEGIN(16, 2);
  LCD_PRINT("Remote Control");
  
  radio.begin();
  radio.setPALevel(RF24_PA_MIN);
  radio.setPayloadSize(sizeof(payload));
  radio.openWritingPipe(address);
  radio.stopListening();
  #ifdef USELEDS
    FastLED.clear();            //clear the LEDs
    FastLED.show();
  #endif
  pinMode(LEFT_JOYSTICK_X_PIN, INPUT);
  pinMode(LEFT_JOYSTICK_Y_PIN, INPUT);
  pinMode(RIGHT_JOYSTICK_X_PIN, INPUT);
  pinMode(RIGHT_JOYSTICK_Y_PIN, INPUT);
  leftButton1.setup(LEFT_BUTTON_1_PIN, INPUT_PULLUP, true);
  leftButton1.attachPress(leftButton1Press);
  rightButton1.setup(RIGHT_BUTTON_1_PIN, INPUT_PULLUP, true);
  rightButton1.attachPress(rightButton1Press);
}

void loop() {
  leftButton1.tick();
  rightButton1.tick();
  #ifdef USELEDS
    display.homingSequence(false);
  #endif
  unsigned long currentMillis = millis();
  static unsigned long previousMillis = 0;
  const unsigned long interval = 50;
  if (currentMillis - previousMillis >= interval) {
    previousMillis = currentMillis;
    readJoysticks();
    radio.write(&payload, sizeof(payload));
    printSerial();
    payload.lb1 = 0;
    payload.rb1 = 0;
  }
}
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

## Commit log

2026-03-12 one-speed control from custom remote
    one-speed control from custom remote (code for remote not included)
    rewired moters, added nrf24l01 receiver and servo
2026-03-12 updated comments and removed some serial debug prints
2026-03-16 changing inverse kinematics and wheel speed functions
2026-03-24 changed servo positions
2026-08-03 work on readme
    [transmitter.fzz]
2026-08-13 add stl, add pictures to readme
    [DOMNO_Servo_Horn.stl, Domino.stl, Magazine.stl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]
